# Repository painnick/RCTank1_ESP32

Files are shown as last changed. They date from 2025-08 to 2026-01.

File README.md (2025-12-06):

# RC 탱크 프로젝트

Bluepad32를 이용한 게임패드 조작 RC 탱크입니다.

## 기능

- **게임패드 연결**: Bluepad32를 통한 블루투스 게임패드 연결
- **트랙 제어**: 좌측 스틱 Y축으로 좌측 트랙, 우측 스틱 Y축으로 우측 트랙 독립 제어
- **터렛 제어**: D-PAD 좌우로 터렛 회전
- **포 마운트 제어**: D-PAD 상하로 포 마운트 각도 조절
- **포신 발사**: B 버튼으로 포신 당기기 (LED 켜짐 + 효과음 2, 200ms)
- **기관총 발사**: A 버튼으로 기관총 발사 (LED 동작 없음 + 효과음 3, 1초간)
- **헤드라이트**: Y 버튼으로 헤드라이트 ON/OFF (100ms 간격)
- **볼륨 조절**: L1 버튼으로 볼륨 감소, R1 버튼으로 볼륨 증가 (EEPROM 저장, 100ms 간격)
- **EEPROM 초기화**: Select + Start 버튼 3초간 누르면 모든 설정 초기화 및 재시작
- **효과음**: DFPlayer를 통한 SD카드 효과음 재생

## 하드웨어 연결

### ESP32 핀 연결

| ESP32 핀 | 연결 대상 | 설명 |
|---|---|---|
| GPIO 4  | 포신 LED | 포신 발사 시 점등, 기관총 발사 시 동작 없음 |
| GPIO 16 | 헤드라이트 LED | 헤드라이트 제어 |
| GPIO 13 | 우측 트랙 IN2 | DRV8833 우측 트랙 제어 |
| GPIO 18 | 포신 서보 모터 | 포신 당기기 제어 (B 버튼) |
| GPIO 19 | 포 마운트 서보 모터 | 포 마운트 각도 제어 (D-PAD 상하) |
| GPIO 21 | 터렛 모터 IN2 | DRV8833 터렛 제어 |
| GPIO 22 | 터렛 모터 IN1 | DRV8833 터렛 제어 |
| GPIO 25 | 좌측 트랙 IN1 | DRV8833 좌측 트랙 제어 |
| GPIO 26 | 좌측 트랙 IN2 | DRV8833 좌측 트랙 제어 |
| GPIO 27 | 우측 트랙 IN1 | DRV8833 우측 트랙 제어 |
| GPIO 32 | DFPlayer RX | DFPlayer 통신 |
| GPIO 33 | DFPlayer TX | DFPlayer 통신 |

### DRV8833 모터 드라이버 연결

#### 좌측 트랙 (DRV8833 #1)
- AIN1 → GPIO 25
- AIN2 → GPIO 26
- AOUT1 → 좌측 트랙 모터 1
- AOUT2 → 좌측 트랙 모터 2
- VM → 12V 전원
- GND → 공통 접지
- VCC → 3.3V (논리 전원)

#### 우측 트랙 (DRV8833 #1)
- BIN1 → GPIO 27
- BIN2 → GPIO 13
- BOUT1 → 우측 트랙 모터 1
- BOUT2 → 우측 트랙 모터 2

#### 터렛 (DRV8833 #2)
- AIN1 → GPIO 22
- AIN2 → GPIO 21
- AOUT1 → 터렛 모터 +
- AOUT2 → 터렛 모터 -
- VM → 12V 전원
- GND → 공통 접지
- VCC → 3.3V (논리 전원)

### 서보 모터 연결

#### 포 마운트 서보 모터 (각도 조절)
- **신호선**: GPIO 19
- **전원**: 5V
- **접지**: 공통 접지
- **기능**: D-PAD 상하로 포 마운트 각도 조절

#### 포신 서보 모터 (당기기)
- **신호선**: GPIO 18
- **전원**: 5V
- **접지**: 공통 접지
- **기능**: B 버튼으로 포신 당기기

### DFPlayer Mini 연결

- RX → GPIO 33
- TX → GPIO 32
- VCC → 5V
- GND → 공통 접지
- SPK_1, SPK_2 → 스피커

## SD카드 설정

SD카드에 다음 파일들을 저장하세요:

```
sdcard/
├── 0001.mp3  (효과음 1 - 대기 시 반복 재생)
├── 0002.mp3  (효과음 2 - 포신 발사 시 재생)
├── 0003.mp3  (효과음 3 - 기관총 발사 시 재생)
└── 0004.mp3  (효과음 4 - 게임 패드 연결 시 재생)
```

## 게임패드 조작법

### 기본 조작
- **좌측 스틱 Y축**: 좌측 트랙 전후진 제어
- **우측 스틱 Y축**: 우측 트랙 전후진 제어
- **D-PAD 좌우**: 터렛 좌우 회전
- **D-PAD 상하**: 포 마운트 상하 각도 조절 (75~135도 범위)

### 버튼 조작
- **B 버튼**: 포신 당기기 (LED 켜짐 + 효과음 2 재생, 200ms)
- **A 버튼**: 기관총 발사 (LED 동작 없음 + 효과음 3 재생, 1초간)
- **Y 버튼**: 헤드라이트 ON/OFF 토글

### 볼륨 조절
- **L1 버튼**: 볼륨 감소 (10-30 범위, 100ms 간격)
- **R1 버튼**: 볼륨 증가 (10-30 범위, 100ms 간격)

*볼륨 설정은 버튼을 뗐을 때 EEPROM에 자동 저장되어 다음 시작 시에도 유지됩니다.*

### 고급 설정

- **Select + Start 버튼 3초간 누르기**: 모든 EEPROM 설정 초기화 및 ESP32 재시작

### LED 동작
- **포신 발사 시**: 포신 LED 지속 점등 (200ms 동안)
- **기관총 발사 시**: 포신 LED 동작 없음
- **헤드라이트**: Y 버튼으로 ON/OFF 토글

### 게임패드 피드백
- **포신 발사 시**: 게임패드 진동 (400ms)
- **기관총 발사 시**: 게임패드 진동 (300ms)

- **EEPROM 초기화 시**: 게임패드 진동 (800ms)
- **볼륨 변경 시**: 시리얼 로그로 확인
- **포 마운트 각도**: 75~135도 범위로 제한 (기존 0~180도에서 개선)
- **포신 발사 시간**: 200ms로 단축 (기존 500ms에서 개선)

## 컴파일 및 업로드

1. PlatformIO IDE에서 프로젝트를 열기
2. 필요한 라이브러리들이 자동으로 설치됩니다
3. ESP32 보드를 연결하고 업로드
4. 시리얼 모니터로 초기화 과정 확인

## 초기화 과정

1. ESP32 부팅
2. EEPROM에서 볼륨 설정 로드
3. 서보 모터 초기화 (포 마운트: 90도, 포신: 90도)
4. DFPlayer 초기화 및 효과음 1 재생 시작
5. Bluepad32 초기화
6. 게임패드 연결 대기

## 게임패드 연결

1. ESP32 부팅 후 블루투스 페어링 모드 진입
2. 게임패드에서 블루투스 설정으로 ESP32 연결
3. 연결 성공 시 효과음 4 재생 및 효과음 1 재생 중단
4. 게임패드 조작 가능

## 게임패드 조작 요약

| 조작 | 기능 | 비고 |
|---|---|---|
| **좌측 스틱 Y축** | 좌측 트랙 전후진 | 독립 제어 |
| **우측 스틱 Y축** | 우측 트랙 전후진 | 독립 제어 |
| **D-PAD 좌우** | 터렛 회전 | 좌우 회전 |
| **D-PAD 상하** | 포 마운트 각도 | 75~135도 |
| **A 버튼** | 기관총 발사 | 1초간, LED 점멸 |
| **B 버튼** | 포신 발사 | 200ms, LED 깜빡임 |

| **L1 + (X 또는 Y) 버튼** | 볼륨 감소 | 10-30 범위 |
| **R1 + (X 또는 Y) 버튼** | 볼륨 증가 | 10-30 범위 |
| **Y 버튼** | 헤드라이트 토글 | ON/OFF |

| **Select + Start (3초)** | EEPROM 초기화 | 재시작 |

## 문제 해결

### 게임패드가 연결되지 않는 경우
- ESP32 재부팅 후 다시 시도
- 게임패드 페어링 정보 초기화 후 재연결

### 모터가 작동하지 않는 경우
- 전원 공급 확인 (12V)
- DRV8833 연결 확인
- PWM 채널 설정 확인

### 효과음이 나오지 않는 경우
- SD카드 파일명 확인 (0001.mp3, 0002.mp3 등)
- DFPlayer 연결 확인 (GPIO 32, 33)
- 볼륨 설정 확인 (코드에서 20으로 설정)

### 서보 모터가 작동하지 않는 경우
- 서보 모터 전원 공급 확인 (5V)
- 서보 신호선 연결 확인 (GPIO 18, GPIO 19)
- ESP32Servo 라이브러리 설치 확인

## 라이센스

이 프로젝트는 MIT 라이센스 하에 배포됩니다.

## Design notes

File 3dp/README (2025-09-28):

# 3D Printing Parts

Considering durability, this part needs to be printed in PETG or ABS.

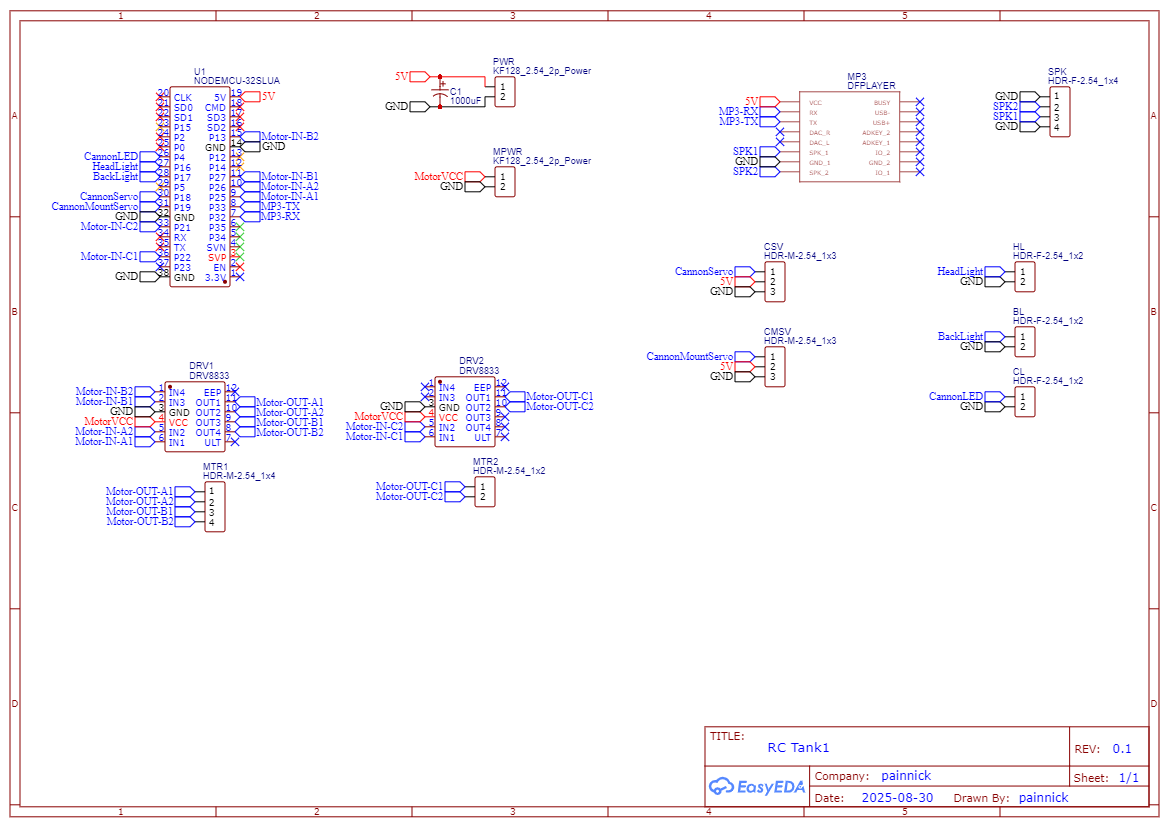
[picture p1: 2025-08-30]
Schematic.png

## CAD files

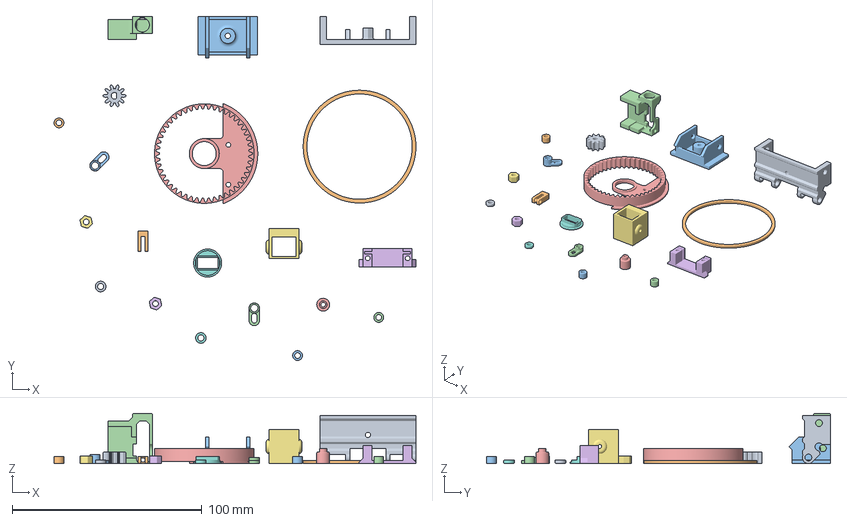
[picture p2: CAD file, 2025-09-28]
3dp/Tiger-I.3mf
190.6 x 181.2 x 26.4 mm
Body v16.step
Turret Guide v4.step
Cover
Frame
Spur Gear (49 teeth)
Cannon Mount Motor Guide v5.step
Motor Holder
Power Switch Holder v2_1
Turret Motor Gear (10 teeth) v3
Cannon Holder2
Cannon Horn
2G Motor Horn v8.step
Cannon Holder
Sproket Nut x2 x 2
Track Sproket x2 x 3

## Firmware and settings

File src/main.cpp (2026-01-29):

#include <Arduino.h>
#include <Bluepad32.h>
#include <DFPlayerMini_Fast.h>
#include <EEPROM.h>
#include <ESP32Servo.h>
#include <driver/mcpwm.h>
#include <esp_log.h>

#ifdef DISABLE_BROWNOUT_DETECTOR
#include <driver/rtc_io.h>
#include <soc/rtc_cntl_reg.h>
#endif

static auto MAIN_TAG = "RC_TANK";

// 핀 정의
#define DFPLAYER_RX 32
#define DFPLAYER_TX 33
#define LEFT_TRACK_IN1 25
#define LEFT_TRACK_IN2 26
#define RIGHT_TRACK_IN1 27
#define RIGHT_TRACK_IN2 13
#define TURRET_IN1 22
#define TURRET_IN2 21
#define CANNON_LED_PIN 4
#define GATLING_LED_PIN 23
#define HEADLIGHT_PIN 16
#define CANNON_MOUNT_SERVO_PIN 19  // 포 마운트 서보 모터 핀 (우측 Y축으로 각도 조절)
#define CANNON_SERVO_PIN 18        // 포신 서보 모터 핀 (A 버튼으로 당기기)

// MCPWM 설정 (모든 모터는 MCPWM_UNIT_0 사용)
#define MCPWM_UNIT MCPWM_UNIT_0
#define LEFT_TRACK_TIMER MCPWM_TIMER_0
#define RIGHT_TRACK_TIMER MCPWM_TIMER_1
#define TURRET_TIMER MCPWM_TIMER_2

// 스틱 데드존(-511~512)
#define STICK_INPUT_MIN (-511)
#define STICK_INPUT_MAX 512
#define STICK_DEAD_ZONE 80

// 모터 듀티(0~100) 데드존
#define MOTOR_DUTY_MIN 0
#define MOTOR_DUTY_MAX 100
#ifndef MOTOR_DEAD_ZONE
#define MOTOR_DEAD_ZONE 65
#endif
constexpr int MOTOR_ACTIVE_DUTY = 100 - MOTOR_DEAD_ZONE;

// 헤드라이트 PWM 설정
#define HEADLIGHT_PWM_CHANNEL 5
#define HEADLIGHT_PWM_FREQ 5000
#define HEADLIGHT_PWM_RESOLUTION 8
#define HEADLIGHT_DUTY_ON 128  // 50% 밝기 (255의 절반)
#define HEADLIGHT_DUTY_OFF 0
#define HEADLIGHT_DUTY_MIN 8
#define HEADLIGHT_DUTY_MAX 255
#define HEADLIGHT_DUTY_STEP 16

// 모터 설정 구조체
typedef struct {
  int in1Pin;
  int in2Pin;
  mcpwm_unit_t unit;
  mcpwm_timer_t timer;
  int& prevSpeed;
  bool& startBoostActive;
  unsigned long& startBoostStartTime;
} MotorConfig;

// EEPROM 주소

#define EEPROM_VOLUME_ADDR 4

// EEPROM 초기화 플래그
#define EEPROM_INIT_FLAG_ADDR 5

// 게임패드 관련 변수
ControllerPtr myControllers[BP32_MAX_GAMEPADS];
bool gamepadConnected = false;

// DFPlayer 관련 변수
DFPlayerMini_Fast myDFPlayer;
HardwareSerial DFPlayerSerial(2); // UART2 사용
unsigned long lastIdleSoundTime = 0;
constexpr unsigned long idleSoundInterval = 13000; // 13초마다 효과음 1 재생

// 서보 모터 객체
Servo cannonMountServo; // 포 마운트 서보 모터
Servo cannonServo; // 포신 서보 모터

// 모터 제어 변수

int leftTrackPWM = 0;
int rightTrackPWM = 0;
int turretPWM = 0;
int cannonMountAngle = 90; // 포 마운트 기본 각도 (중앙)
constexpr int cannonAngle = 90; // 포신 기본 각도 (중앙)

// 볼륨 제어 변수
int currentVolume = 20; // 현재 볼륨 (1-30)
int tempVolume = 20; // 임시 볼륨 (버튼을 누르고 있는 동안 사용)
bool volumeChanged = false; // 볼륨이 변경되었는지 확인

// DC 모터 이전 속도 값 저장 변수
int prevLeftTrackSpeed = 0;
int prevRightTrackSpeed = 0;
int prevTurretSpeed = 0;

// 트랙 시동 부스트: 정지 후 500ms 동안 80% 듀티
constexpr int trackStartBoostDuty = 80;
constexpr unsigned long trackStartBoostDuration = 500;
bool leftTrackStartBoostActive = false;
bool rightTrackStartBoostActive = false;
unsigned long leftTrackStartBoostStartTime = 0;
unsigned long rightTrackStartBoostStartTime = 0;

// 모터 설정 구조체 인스턴스
MotorConfig leftTrackMotor = {.in1Pin = LEFT_TRACK_IN1,
                              .in2Pin = LEFT_TRACK_IN2,
                              .unit = MCPWM_UNIT,
                              .timer = LEFT_TRACK_TIMER,
                              .prevSpeed = prevLeftTrackSpeed,
                              .startBoostActive = leftTrackStartBoostActive,
                              .startBoostStartTime = leftTrackStartBoostStartTime};

MotorConfig rightTrackMotor = {.in1Pin = RIGHT_TRACK_IN1,
                               .in2Pin = RIGHT_TRACK_IN2,
                               .unit = MCPWM_UNIT,
                               .timer = RIGHT_TRACK_TIMER,
                               .prevSpeed = prevRightTrackSpeed,
                               .startBoostActive = rightTrackStartBoostActive,
                               .startBoostStartTime = rightTrackStartBoostStartTime};

boolean turretBoostActive = false;
unsigned long turretBoostStartTime = 0;
MotorConfig turretMotor = {.in1Pin = TURRET_IN1,
                           .in2Pin = TURRET_IN2,
                           .unit = MCPWM_UNIT,
                           .timer = TURRET_TIMER,
                           .prevSpeed = prevTurretSpeed,
                           .startBoostActive = turretBoostActive,
                           .startBoostStartTime = turretBoostStartTime};

// LED 상태
bool headlightOn = false;
int headlightDuty = 0; // 현재 헤드라이트 밝기 (0~255)
unsigned long lastBlinkTime = 0;
constexpr unsigned long blinkInterval = 100; // 100ms 간격으로 깜빡임

// 포신 발사 관련 변수
bool cannonFiring = false;
unsigned long cannonStartTime = 0;
constexpr unsigned long cannonDuration = 1500; // 1초 동안 포신 당김 (재발사 방지 쿨타임 역할)
constexpr unsigned long cannonLedDuration = 200; // LED는 200ms만 켜짐

// 기관총 발사 관련 변수
bool machineGunFiring = false;
unsigned long machineGunStartTime = 0;
constexpr unsigned long machineGunDuration = 600; // 1초간 기관총 발사

// 효과음 파일 번호
#define SOUND_IDLE 1
#define SOUND_CANNON 2
#define SOUND_MACHINEGUN 3
#define SOUND_CONNECTED 4

// 게임패드 연결 콜백
void onConnectedController(ControllerPtr ctl) {
  bool foundEmptySlot = false;
  for (int i = 0; i < BP32_MAX_GAMEPADS; i++) {
    if (myControllers[i] == nullptr) {
      ESP_LOGI(MAIN_TAG, "Gamepad connected, index=%d", i);
      const ControllerProperties properties = ctl->getProperties();
      ESP_LOGI(MAIN_TAG, "Controller model: %s, VID=0x%04x, PID=0x%04x",
               ctl->getModelName().c_str(),
               properties.vendor_id,
               properties.product_id);
      myControllers[i] = ctl;
      foundEmptySlot = true;
      gamepadConnected = true;

      // 게임 패드 진동
      ctl->playDualRumble(0, 300, 0xFF, 0x0);

      // 게임패드 연결 시 효과음 4 재생
      myDFPlayer.play(SOUND_CONNECTED);
      break;
    }
  }
  if (!foundEmptySlot) {
    ESP_LOGW(MAIN_TAG, "Gamepad connected, but no empty slot found");
  }
}

// 게임패드 연결 해제 콜백
void onDisconnectedController(ControllerPtr ctl) {
  bool foundController = false;
  for (int i = 0; i < BP32_MAX_GAMEPADS; i++) {
    if (myControllers[i] == ctl) {
      ESP_LOGI(MAIN_TAG, "Gamepad disconnected, index=%d", i);
      myControllers[i] = nullptr;
      foundController = true;
      break;
    }
  }

  // 모든 게임패드가 연결 해제되었는지 확인
  gamepadConnected = false;
  for (const auto& myController : myControllers) {
    if (myController != nullptr) {
      gamepadConnected = true;
      break;
    }
  }

  if (!gamepadConnected) {
    // 모든 게임패드가 연결 해제되면 효과음 1 재생 시작
    myDFPlayer.play(SOUND_IDLE);
    lastIdleSoundTime = millis();
  }

  if (!foundController) {
    ESP_LOGW(MAIN_TAG, "Gamepad disconnected, but not found in myControllers");
  }
}

// DC 모터 제어 함수 (MCPWM 사용, 속도 변화가 없으면 호출 무시)
// stick : -511~512
// motor duty : 0~100
void setMotorSpeed(const MotorConfig& motor, const int stick, boolean force = false) {
  int duty = 0;
  const int absStick = abs(stick);
  if (absStick < STICK_DEAD_ZONE) {
    duty = MOTOR_DUTY_MIN;
  } else if (absStick > 500) {
    duty = stick > 0 ? MOTOR_DUTY_MAX : -MOTOR_DUTY_MAX;
  } else {
    const auto sanitizedStick = stick - STICK_DEAD_ZONE;
    duty = map(sanitizedStick,
               STICK_INPUT_MIN + STICK_DEAD_ZONE,
               STICK_INPUT_MAX - STICK_DEAD_ZONE,
               MOTOR_ACTIVE_DUTY * -1,
               MOTOR_ACTIVE_DUTY);
    if (duty > 0)
      duty += MOTOR_DEAD_ZONE;
    else
      duty -= MOTOR_DEAD_ZONE;
  }

  if (!force) {
    // 트랙 시동 부스트: 정지 후 움직이기 시작할 때 500ms 동안 80% 듀티로 가동
    if (motor.startBoostActive && motor.startBoostStartTime) {
      if (duty != 0 && motor.prevSpeed == 0) {
        motor.startBoostActive = true;
        motor.startBoostStartTime = millis();
      }
      const unsigned long now = millis();
      if (now - motor.startBoostStartTime < trackStartBoostDuration) {
        duty = (duty > 0) ? trackStartBoostDuty : -trackStartBoostDuty;
      } else {
        motor.startBoostActive = false;
      }
      if (duty == 0) {
        motor.startBoostActive = false;
      }
    }
  } else {
    motor.startBoostActive = false;
  }

  // 속도 변화가 없으면 호출 무시
  if (duty == motor.prevSpeed) {
    return;
  }

  ESP_LOGD(MAIN_TAG,
           "setMotorSpeed IN1:%d IN2:%d Unit:%d Timer:%d Stick:%d Duty:%3d (prev:%d)",
           motor.in1Pin, motor.in2Pin, motor.unit, motor.timer, stick, duty, motor.prevSpeed);

  if (duty > 0) {
    // 정방향 회전
    mcpwm_set_duty(motor.unit, motor.timer, MCPWM_OPR_A, 100);
    mcpwm_set_duty(motor.unit, motor.timer, MCPWM_OPR_B, 100 - static_cast<float>(duty));
  } else if (duty < 0) {
    // 역방향 회전
    mcpwm_set_duty(motor.unit, motor.timer, MCPWM_OPR_A, 100 + static_cast<float>(duty));
    mcpwm_set_duty(motor.unit, motor.timer, MCPWM_OPR_B, 100);
  } else {
    // 정지
    mcpwm_set_duty(motor.unit, motor.timer, MCPWM_OPR_A, 100);
    mcpwm_set_duty(motor.unit, motor.timer, MCPWM_OPR_B, 100);
  }

  // 현재 속도를 이전 속도로 저장
  motor.prevSpeed = duty;
}

// 포 마운트 서보 모터 제어 함수
void setCannonMountAngle(const int angle) {
  ESP_LOGD(MAIN_TAG, "Cannon-Mount Angle %3d degree", angle);
  cannonMountServo.write(angle);
}

// 포신 서보 모터 제어 함수
void setCannonAngle(const int angle) {
  ESP_LOGD(MAIN_TAG, "Cannon Angle %3d degree", angle);
  cannonServo.write(angle);
}

// 볼륨 설정 저장
void saveVolumeSettings() {
  EEPROM.write(EEPROM_VOLUME_ADDR, currentVolume);
  EEPROM.commit();
  ESP_LOGI(MAIN_TAG, "Volume setting saved: %d", currentVolume);
}

// 볼륨 설정 로드
void loadVolumeSettings() {
  int volume = EEPROM.read(EEPROM_VOLUME_ADDR);

  // 기본값 설정 (EEPROM이 초기화되지 않은 경우)
  if (volume < 10 || volume > 30) {
    volume = 20; // 기본 볼륨 20
    EEPROM.write(EEPROM_VOLUME_ADDR, volume);
    EEPROM.commit();
  }

  currentVolume = volume;
  tempVolume = volume;
  myDFPlayer.volume(currentVolume);
  ESP_LOGI(MAIN_TAG, "Volume setting loaded: %d", currentVolume);
}

// EEPROM 초기화 및 ESP32 재시작
void resetEEPROMAndRestart() {
  ESP_LOGI(MAIN_TAG, "EEPROM 초기화 및 재시작 시작...");

  // 모든 EEPROM 데이터 초기화
  for (int i = 0; i < 512; i++) {
    EEPROM.write(i, 0);
  }
  EEPROM.commit();

  ESP_LOGI(MAIN_TAG, "EEPROM 초기화 완료. 3초 후 재시작합니다.");

  // 3초 대기 후 재시작
  delay(3000);
  esp_restart();
}

void dumpGamepad(ControllerPtr ctl) {
  // clang-format off
  ESP_LOGV(MAIN_TAG,
           "0x%02x %s %s %s %s %s %s %s %s %s %s %s %s %s %s misc: 0x%02x LY:%3d RY:%3d",
           ctl->dpad(),
           ctl->a() ? "A" : "-",
           ctl->b() ? "B" : "-",
           ctl->x() ? "X" : "-",
           ctl->y() ? "Y" : "-",
           ctl->l1() ? "L1" : "--",
           ctl->r1() ? "R1" : "--",
           ctl->l2() ? "L2" : "--",
           ctl->r2() ? "R2" : "--",
           ctl->thumbL() ? "ThumbL" : "------",
           ctl->thumbR() ? "ThumbR" : "------",
           ctl->miscStart() ? "Start" : "------",
           ctl->miscSelect() ? "Select" : "------",
           ctl->miscSystem() ? "System" : "------",
           ctl->miscCapture() ? "Capture" : "------",
           ctl->miscButtons(),
           ctl->axisY(),
           ctl->axisRY());
  // clang-format on
}

// 게임패드 처리 함수
void processGamepad(ControllerPtr ctl) {
  dumpGamepad(ctl);

  // 좌측 스틱 Y축으로 좌측 트랙 제어, 우측 스틱 Y축으로 우측 트랙 제어

  // 모터 제어
  setMotorSpeed(leftTrackMotor, ctl->axisY());
  setMotorSpeed(rightTrackMotor, ctl->axisRY());

  // D-PAD로 터렛과 포 마운트 제어
  // D-PAD 좌우로 터렛 제어
  int turretSpeed = 0;
  if (ctl->dpad() == DPAD_LEFT) {
    turretSpeed = STICK_INPUT_MIN; // 좌측 회전
  } else if (ctl->dpad() == DPAD_RIGHT) {
    turretSpeed = STICK_INPUT_MAX; // 우측 회전
  }
  setMotorSpeed(turretMotor, turretSpeed);

  // D-PAD 상하로 포 마운트 각도 제어
  if (ctl->dpad() == DPAD_UP) {
    cannonMountAngle = constrain(cannonMountAngle + 2, 75, 160); // 위로 올림
    setCannonMountAngle(cannonMountAngle);
  } else if (ctl->dpad() == DPAD_DOWN) {
    cannonMountAngle = constrain(cannonMountAngle - 2, 75, 160); // 아래로 내림
    setCannonMountAngle(cannonMountAngle);
  }

  // B 버튼으로 포신 발사
  if (ctl->b() && !cannonFiring && !machineGunFiring) {
    cannonFiring = true;
    cannonStartTime = millis();
    // 포신 발사 중에는 LED를 지속 점등
    digitalWrite(CANNON_LED_PIN, HIGH);

    // 효과음 2 재생
    myDFPlayer.play(SOUND_CANNON);

    // 게임 패드 진동
    ctl->playDualRumble(0, 500, 0xFF, 0xFF);

    cannonServo.attach(CANNON_SERVO_PIN); // 포신 서보 모터
    delay(100);
    // 포신 당기기
    setCannonAngle(cannonAngle - 90); // 포신을 아래로 당김

    digitalWrite(CANNON_LED_PIN, LOW);

    delay(100);

    setMotorSpeed(leftTrackMotor, 256 + 64, true);
    setMotorSpeed(rightTrackMotor, 256 + 64, true);

    delay(100);

    setMotorSpeed(leftTrackMotor, 0);
    setMotorSpeed(rightTrackMotor, 0);

    delay(200);

    setCannonAngle(cannonAngle); // 포신을 원래 위치로 복원

    delay(300);
    cannonServo.detach(); // 포신 서보 모터
  }

  // A 버튼으로 기관총 발사
  if (ctl->a() && !machineGunFiring && !cannonFiring) {
    machineGunFiring = true;
    machineGunStartTime = millis();

    // 효과음 3 재생
    myDFPlayer.play(SOUND_MACHINEGUN);

    delay(500);

    // 게임 패드 진동
    ctl->playDualRumble(0, 300, 0xFF, 0x0);

    for (int i = 0; i < 4; i++) {
      digitalWrite(GATLING_LED_PIN, HIGH);
      delay(100);
      digitalWrite(GATLING_LED_PIN, LOW);
      if (i < 3)
        delay(100);
    }
  }

  // L1 버튼으로 볼륨 조절 (둔감하게 처리)
  static bool l1ButtonPressed = false;
  static bool r1ButtonPressed = false;
  static unsigned long l1LastChangeTime = 0;
  static unsigned long r1LastChangeTime = 0;
  constexpr unsigned long volumeChangeInterval = 100; // 100ms 간격으로 볼륨 변경

  // L1 버튼으로 볼륨 감소 (Y 버튼이 눌리지 않았을 때만)
  if (ctl->l1() && !ctl->y()) {
    if (!l1ButtonPressed) {
      l1ButtonPressed = true;
      tempVolume = currentVolume; // 현재 볼륨을 임시 볼륨으로 복사
      l1LastChangeTime = millis();
    }

    // 볼륨 감소 (1-30 범위)
    if (tempVolume > 1 &&
        (millis() - l1LastChangeTime >= volumeChangeInterval)) {
      tempVolume--;
      l1LastChangeTime = millis();
      ESP_LOGI(MAIN_TAG, "Volume decreased to: %d", tempVolume);
    }
  } else if (!ctl->l1()) {
    // L1 버튼 해제 시에만 처리
    if (l1ButtonPressed) {
      l1ButtonPressed = false;
      // L1 버튼을 뗐을 때 볼륨 변경사항 저장
      if (tempVolume != currentVolume) {
        currentVolume = constrain(tempVolume, 10, 30);
        myDFPlayer.volume(currentVolume); // DFPlayer 볼륨 적용
        volumeChanged = true;
        ESP_LOGI(MAIN_TAG, "Volume change confirmed: %d", currentVolume);
      }
    }
  }

  // R1 버튼으로 볼륨 증가 (Y 버튼이 눌리지 않았을 때만)
  if (ctl->r1() && !ctl->y()) {
    if (!r1ButtonPressed) {
      r1ButtonPressed = true;
      tempVolume = currentVolume; // 현재 볼륨을 임시 볼륨으로 복사
      r1LastChangeTime = millis();
    }

    // 볼륨 증가 (1-30 범위)
    if (tempVolume < 30 &&
        (millis() - r1LastChangeTime >= volumeChangeInterval)) {
      tempVolume++;
      r1LastChangeTime = millis();
      ESP_LOGI(MAIN_TAG, "Volume increased to: %d", tempVolume);
    }
  } else if (!ctl->r1()) {
    // R1 버튼 해제 시에만 처리
    if (r1ButtonPressed) {
      r1ButtonPressed = false;
      // R1 버튼을 뗐을 때 볼륨 변경사항 저장
      if (tempVolume != currentVolume) {
        currentVolume = constrain(tempVolume, 10, 30);
        myDFPlayer.volume(currentVolume); // DFPlayer 볼륨 적용
        volumeChanged = true;
        ESP_LOGI(MAIN_TAG, "Volume change confirmed: %d", currentVolume);
      }
    }
  }

  // 볼륨이 변경되었으면 EEPROM에 저장
  if (volumeChanged) {
    saveVolumeSettings();
    volumeChanged = false;
  }

  // 헤드라이트 제어 관련 변수
  static bool yButtonPressed = false;
  static unsigned long lastBrightnessChangeTime = 0;

  // Y 버튼 처리 (밝기 조절 및 토글)
  if (ctl->y()) {
    // 1. 밝기 조절 (L1/R1과 조합)
    if (ctl->l1() || ctl->r1()) {
      constexpr unsigned long brightnessChangeInterval = 200;
      if (millis() - lastBrightnessChangeTime >= brightnessChangeInterval) {
        if (ctl->l1()) {
          headlightDuty = constrain(headlightDuty - HEADLIGHT_DUTY_STEP, HEADLIGHT_DUTY_MIN, HEADLIGHT_DUTY_MAX);
          ESP_LOGI(MAIN_TAG, "Headlight Brightness Decreased: %d", headlightDuty);
        }
        if (ctl->r1()) {
          headlightDuty = constrain(headlightDuty + HEADLIGHT_DUTY_STEP, HEADLIGHT_DUTY_MIN, HEADLIGHT_DUTY_MAX);
          ESP_LOGI(MAIN_TAG, "Headlight Brightness Increased: %d", headlightDuty);
        }
        // 현재 켜져있다면 즉시 적용
        if (headlightOn) {
          ledcWrite(HEADLIGHT_PWM_CHANNEL, headlightDuty);
        }
        lastBrightnessChangeTime = millis();
      }
      // 밝기 조절 중에는 토글 방지를 위해 pressed 상태 유지
      yButtonPressed = true;
    }
    // 2. 헤드라이트 토글 (단독 누름, 최초 눌림 시점)
    else if (!yButtonPressed) {
      yButtonPressed = true;
      headlightOn = !headlightOn;
      if (headlightOn && headlightDuty < HEADLIGHT_DUTY_MIN)
        headlightDuty = HEADLIGHT_DUTY_MIN;
      ledcWrite(HEADLIGHT_PWM_CHANNEL, headlightOn ? headlightDuty : HEADLIGHT_DUTY_OFF);
      ESP_LOGI(MAIN_TAG, "Headlight is %s (Duty: %d)", headlightOn ? "On" : "Off", headlightDuty);
    }
  } else {
    yButtonPressed = false;
  }

  // Select + Start 버튼 3초 이상 동시 누름으로 EEPROM 초기화 및 재시작
  static bool selectStartPressed = false;
  static unsigned long selectStartStartTime = 0;

  if (ctl->miscSelect() && ctl->miscStart()) {
    if (!selectStartPressed) {
      selectStartPressed = true;
      selectStartStartTime = millis();
      ESP_LOGI(MAIN_TAG, "Select + Start 버튼이 눌렸습니다. 3초간 유지하면 EEPROM 초기화가 시작됩니다.");
    } else {
      constexpr unsigned long selectStartHoldDuration = 3000;
      // 버튼이 계속 눌려있는 상태에서 3초 경과 확인
      if (millis() - selectStartStartTime >= selectStartHoldDuration) {
        ESP_LOGI(MAIN_TAG, "Select + Start 버튼을 3초간 누르셨습니다. EEPROM 초기화를 시작합니다.");

        // 게임패드 진동으로 확인 신호
        ctl->playDualRumble(0, 800, 0xFF, 0x0);

        // EEPROM 초기화 및 재시작
        resetEEPROMAndRestart();
      }
    }
  } else {
    selectStartPressed = false;
  }
}

// 포신 발사 처리
void processCannonFiring() {
  if (cannonFiring) {
    const unsigned long currentTime = millis();

    if (currentTime - cannonStartTime >= cannonDuration) {
      // 포신 발사 완료 (쿨타임 종료)
      cannonFiring = false;

      // 효과음 1 재생 재개 (게임패드가 연결되어 있지 않은 경우)
      if (!gamepadConnected && !machineGunFiring) {
        myDFPlayer.play(SOUND_IDLE);
        lastIdleSoundTime = millis();
      }
    }
  }
}

// 기관총 발사 처리
void processMachineGunFiring() {
  if (machineGunFiring) {
    const unsigned long currentTime = millis();
    if (currentTime - machineGunStartTime >= machineGunDuration) {
      // 기관총 발사 완료
      machineGunFiring = false;

      // 효과음 1 재생 재개 (게임패드가 연결되어 있지 않은 경우)
      if (!gamepadConnected && !cannonFiring) {
        myDFPlayer.play(SOUND_IDLE);
        lastIdleSoundTime = millis();
      }
    }
  }
}

// 효과음 반복 재생 처리
void processIdleSound() {
  if (!gamepadConnected && !cannonFiring && !machineGunFiring) {
    const unsigned long currentTime = millis();
    if (currentTime - lastIdleSoundTime >= idleSoundInterval) {
      myDFPlayer.play(SOUND_IDLE);
      lastIdleSoundTime = currentTime;
    }
  }
}

// 모든 컨트롤러 처리
void processControllers() {
  for (const auto myController : myControllers) {
    if (myController && myController->isConnected() &&
        myController->hasData()) {
      if (myController->isGamepad()) {
        processGamepad(myController);
      }
    }
  }
}

// 설정 함수
void setup() {
  ESP_LOGI(MAIN_TAG, "RC Tank Initialization...");
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
void loop() {
  // Bluepad32 업데이트
  const bool dataUpdated = BP32.update();
  if (dataUpdated) {
    processControllers();
  }

  // 포신 발사 처리
  processCannonFiring();

  // 기관총 발사 처리
  processMachineGunFiring();

  // 효과음 반복 재생 처리
  processIdleSound();

  delay(10); // 10ms 딜레이
}

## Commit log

2025-08-29 ADD. RC 탱크 프로젝트 초기화 및 기능 추가: 게임패드 연결, 트랙 및 터렛 제어, 포신 발사 기능 구현. README.md 파일 추가 및 라이브러리 의존성 설정.
2025-08-29 CHANGE. 라이브러리 변경 및 README 업데이트: Adafruit PWM Servo Driver 라이브러리를 ESP32Servo로 교체하고, 포신 서보 모터 연결 및 설정에 대한 내용을 README.md에 추가함.
2025-08-29 UPDATE. README 및 코드 수정: 포신 발사 기능을 '포 당기기'로 변경하고, 관련 핀 및 서보 모터 설정을 추가하여 코드와 문서 일치시킴.
    [main.cpp]
2025-08-29 UPDATE. README 및 코드 수정: '포신'과 '포 마운트' 관련 용어를 일관되게 변경하고, 서보 모터 핀 및 기능 설명을 수정하여 문서와 코드의 일치를 강화함.
    [main.cpp]
2025-08-29 ADD. 모니터링 속도 설정
2025-08-29 ADD. 발포 시 게임 패드 진동 추가
2025-08-29 UPDATE. CPU 클록을 160 MHz로 낮춰 Brownout 방지 기능 추가
    [main.cpp]
2025-08-29 UPDATE. 모니터링 설정 변경
2025-08-29 UPDATE. README 및 코드 수정: DFPlayer 연결 핀 번호를 변경하고, 관련 설명을 업데이트하여 문서와 코드의 일치를 강화함.
    [main.cpp]
2025-08-29 BUGFIX. 효과음 재생 직전에 stop 명령 제거
    [main.cpp]
2025-08-29 CHANGE. PIN 번호
2025-08-29 UPDATE. ESP_LOG를 사용하여 디버깅 정보를 개선하고, 빌드 플래그를 추가하여 로그 레벨을 조정함.
2025-08-29 UPDATE. 모터 제어 함수의 PWM 채널 정의를 변경하고, 관련된 모든 호출을 수정하여 코드의 일관성을 강화함. 초기화 과정에서 모터 속도를 0으로 설정하는 로직 추가.
    [main.cpp]
2025-08-29 UPDATE. DC 모터의 최소 속도 임계값을 정의하고, 모터 속도 설정 함수에 해당 임계값을 적용하여 속도 제어 로직을 개선함.
2025-08-29 UPDATE. DC 모터 제어 함수에 이전 속도 값을 저장하고, 속도 변화가 없을 경우 호출을 무시하는 로직을 추가하여 성능을 개선함.
2025-08-29 UPDATE. 효과음 재생 시간 수정
    [main.cpp]
2025-08-29 UPDATE. MCPWM을 사용하여 DC 모터 제어 방식을 개선하고, 관련된 모든 호출을 수정하여 코드의 일관성을 강화함. 초기화 과정에서 모터 속도를 0으로 설정하는 로직 추가.
    [main.cpp]
2025-08-30 UPDATE. README 및 코드 수정: 게임패드 조작 방식 변경 및 기관총 발사 기능 추가, LED 동작 및 효과음 관련 설명 업데이트.
    [main.cpp]
2025-08-30 ADD. 배선도 추가
2025-08-30 UPDATE. 게임 패드 연결 시 효과음 재생
2025-08-30 UPDATE. README 및 코드 수정: 버튼 조작 방식 변경 및 속도 조절 기능 개선.
    [main.cpp]
2025-08-30 UPDATE. README 및 코드 수정: 속도 조절 기능을 배율 기반으로 변경하고, 관련 설명 및 EEPROM 저장 방식을 업데이트함.
    [main.cpp]
2025-08-30 UPDATE. MCPWM 유닛 및 타이머 설정을 통일하여 코드 일관성을 강화하고, 주석을 추가하여 이해도를 높임.
2025-08-30 UPDATE. 기관총 발사 시간 조정
2025-08-30 UPDATE. README 및 코드 수정: GPIO 핀 번호 변경 및 관련 설명 업데이트.
    [main.cpp]
2025-08-30 REMOVE. 배선도
2025-08-30 UPDATE. README 및 코드 수정: A/B 버튼 기능 변경 및 속도 조절 버튼 매핑 수정.
    [main.cpp]
2025-08-30 UPDATE. README 및 코드 수정: GPIO 핀 번호 변경, 포신 LED 및 헤드라이트 핀 설명 업데이트, 서보 모터 신호선 수정.
    [main.cpp]
2025-08-30 ADD. Schematic
2025-09-01 UPDATE. MCPWM 설정을 통합하고 모터 설정 구조체를 추가하여 코드 가독성을 향상시킴. 모터 속도 제어 함수를 구조체 기반으로 수정.
    [main.cpp]
2025-09-01 UPDATE. DC 모터 최소 속도 임계값을 50에서 80으로 변경하여 성능 조정. 코드 가독성을 위해 불필요한 공백 제거.
2025-09-01 UPDATE. 코드 가독성을 높이기 위해 const 및 auto 키워드를 사용하여 변수 선언 방식을 개선하고, 불필요한 공백을 제거함. 게임패드 처리 로직을 개선하여 버튼 매핑 및 속도 조절 기능을 수정함.
    [main.cpp]
2025-09-01 ADD. EEPROM 초기화 기능 추가 및 Select + Start 버튼으로 초기화 트리거 구현. EEPROM 초기화 플래그 설정 로직 추가.
2025-09-01 ADD. 버튼 스왑 기능 추가: A/B 및 X/Y 버튼의 스왑 설정을 EEPROM에 저장하고 로드하는 기능 구현. L1 + R1 버튼을 3초 이상 누르면 버튼 스왑 활성화/비활성화 기능 추가.
2025-09-01 UPDATE. README 수정: 버튼 기능 및 조작 방법 변경, 버튼 스왑 및 EEPROM 초기화 기능 추가, 게임패드 조작 요약 섹션 추가.
2025-09-01 UPDATE. README 및 코드 수정: Select + Start 버튼으로 EEPROM 초기화 시 3초 유지 필요하도록 변경, 관련 로직 및 설명 업데이트.
    [main.cpp]
2025-09-01 UPDATE. Log Level 수정
2025-09-01 UPDATE. README 및 코드 수정: 헤드라이트 토글 버튼 변경, 볼륨 조절 기능 추가 및 관련 로직 업데이트. EEPROM에서 볼륨 설정 로드 및 저장 기능 구현.
    [main.cpp]
2025-09-01 UPDATE. README 및 코드 수정: 볼륨 조절 범위를 0-30에서 1-30으로 변경하고, 관련 로직을 업데이트하여 볼륨 조절 기능의 일관성을 개선함.
    [main.cpp]
2025-09-01 UPDATE. README 및 코드 수정: 볼륨 조절 버튼을 L1 + (X 또는 Y) 및 R1 + (X 또는 Y)로 변경하여 일관성을 개선하고, 관련 설명을 업데이트함.
    [main.cpp]
2025-09-01 UPDATE. README 및 코드 수정: 버튼 스왑 기능을 L2 + R2에서 L1 + R1으로 변경하고, 관련 설명 및 로직을 업데이트하여 일관성을 개선함.
    [main.cpp]
2025-09-01 UPDATE. 볼륨 변경 간격을 200ms에서 100ms로 수정하여 볼륨 조절 반응성을 개선함.
    [main.cpp]
2025-09-02 UPDATE. README 및 코드 수정: 포신 발사 시간을 200ms로 단축하고, 포 마운트 각도를 75~110도로 제한하여 조작의 일관성을 개선함. 볼륨 조절 감도를 100ms 간격으로 변경하여 반응성을 향상시킴.
    [main.cpp]
2025-09-21 CHANGE. Pin No
2025-09-28 ADD. 3D parts
    [Tiger-I.3mf]
2025-09-28 UPDATE. 3D parts
    [Tiger-I.3mf]
2025-10-20 CHANGE. v2 보드에 맞춘 핀 변경
2025-10-20 REMOVE. LED 점멸 관련 변수 및 함수 삭제, 포신 발사 중 LED 지속 점등으로 변경하여 코드 간소화
2025-10-20 UPDATE. 포 마운트 각도의 상한을 110도에서 135도로 변경하여 조작 범위를 확장함.
2025-10-20 UPDATE. README 수정: 포신 발사 시 LED 동작을 지속 점등으로 변경하고, 기관총 발사 시 LED 동작을 없음으로 수정. 포 마운트 각도 범위를 75~135도로 확장하여 조작 범위를 개선함.
2025-11-23 ADD. Brownout Detector Disable
    [main.cpp]
2025-11-28 CHANGE. 포신 발사 대기 시간 변경(200ms -> 1,000ms)
2025-11-28 UPDATE. 발포 시간 제한 및 LED 표시 시간 설정
2025-12-01 CHANGE. 포신 발포 액션
2025-12-01 CHANGE. 포신 각도 제한 수정
    [main.cpp]
2025-12-04 CHANGE. 기관총 발사 시간 변경
2025-12-06 REMOVE. 버튼 스왑 기능 제거
2025-12-06 REMOVE. 트랙 속도 비율 조정 제거
2025-12-06 CHANGE. 트랙 제어 방식 변경
2025-12-06 CHANGE. 헤드 라이드 제어 방식 변경
2025-12-06 CHANGE. 모터 구동 Duty
2025-12-06 CHANGE. 대포 발사 액션
2025-12-06 FIX. 터렛 회전 속도
    [main.cpp]
2025-12-06 CHANGE. 볼륨 제어
2025-12-07 CHANGE. 헤드 라이트 밝기를 PWM 방식으로 변경
2025-12-07 CHANGE. 헤드 라이트 LEDC Ch
2025-12-07 ADD. 헤드 라이트 밝기 조절
2025-12-08 FIX. Motor Speed
2025-12-08 UPDATE. 발포 효과 수정
    [main.cpp]
2025-12-08 ADD. Kick start 기능 추가
2025-12-09 ADD. 기기별 설정 처리
2025-12-09 UPDATE. 포 발사 시 전류 소모를 줄이기
2025-12-09 UPDATE. 포 발사 간격을 늘려서 전류 소모 줄이기
2025-12-24 UPDATE. Slow Decay 적용
2026-01-29 FIX. 개틀링 액션
